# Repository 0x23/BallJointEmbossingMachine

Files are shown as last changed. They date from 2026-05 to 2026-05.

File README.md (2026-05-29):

# Ball Joint Embossing Machine

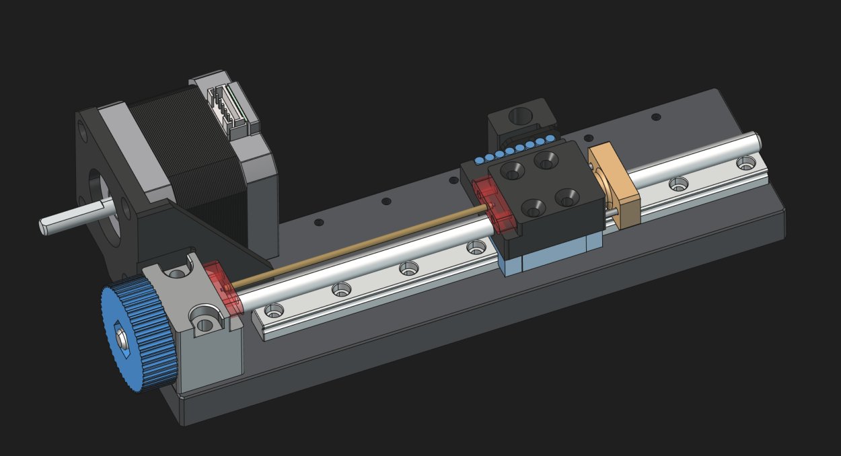
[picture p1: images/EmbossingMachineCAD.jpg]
CAD render of the embossing machine


> **Work in Progress** — This project is not in a finished, well-documented, or ready-to-replicate state. It is shared as a starting point for anyone who wants to build upon it. Expect incomplete documentation, rough edges, and parts that may require adaptation.

## Overview

A motorized linear embossing machine designed to precisely press ball joints. It was designed to automate the production of balljoint linkages for the [Open-Micro-Manipulator](https://github.com/0x23/MicroManipulatorStepper). It uses a NEMA 17 stepper motor driving a leadscrew on an MGN9 linear rail, with closed-loop position feedback from an MT6835 magnetic encoder. The tool head position is controlled in real time by firmware running on an RP2040 microcontroller.

Watch the video on YouTube (https://youtu.be/NM2KXvRGmpg)

## Hardware

- **Microcontroller:** RP2040-ZERO / RP2350-ZERO
- **Motor:** NEMA 17 stepper (1.8°, 50 pole pairs)
- **Motor driver:** TB6612
- **Position sensor:** MT6835 magnetic encoder (SPI)
- **Linear guide:** MGN9 rail + carriage
- **Drive:** Leadscrew with 3 mm magnet pitch, 48/20 gear ratio

## Electronics

> **WARNING: The electronics must be powered by no more than 5 V. Supplying a higher voltage will risk damaging the USB port on your Computer.**

The custom controller board (`electronics/ControllerBoardSingle_v1/`) is designed around the RP2040-ZERO / RP2350-ZERO and the TB6612 dual motor driver. Open the project with KiCad 10 or later. There is alwas a physical button to start the embossing process - please look at the firmware for finding the correct pin.

## Firmware

The firmware is built with [PlatformIO](https://platformio.org/).

**Build & upload:**
```bash
cd firmware
pio run --target upload
```

**Linux note:** udev rules must be installed before the upload will work:
```bash
sudo curl -fsSL https://raw.githubusercontent.com/platformio/platformio-core/develop/platformio/assets/system/99-platformio-udev.rules \
  -o /etc/udev/rules.d/99-platformio-udev.rules
sudo service udev restart
# replug the device, then run pio run --target upload
```

## License

MIT — see [LICENSE](LICENSE) for the full text.

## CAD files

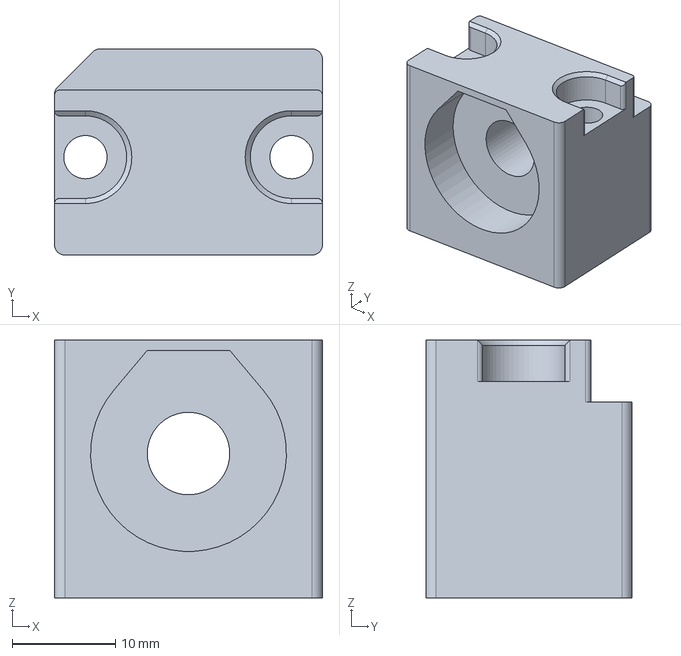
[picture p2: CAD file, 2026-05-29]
construction/ToolpostFixed.FCStd
26.0 x 20.0 x 25.0 mm

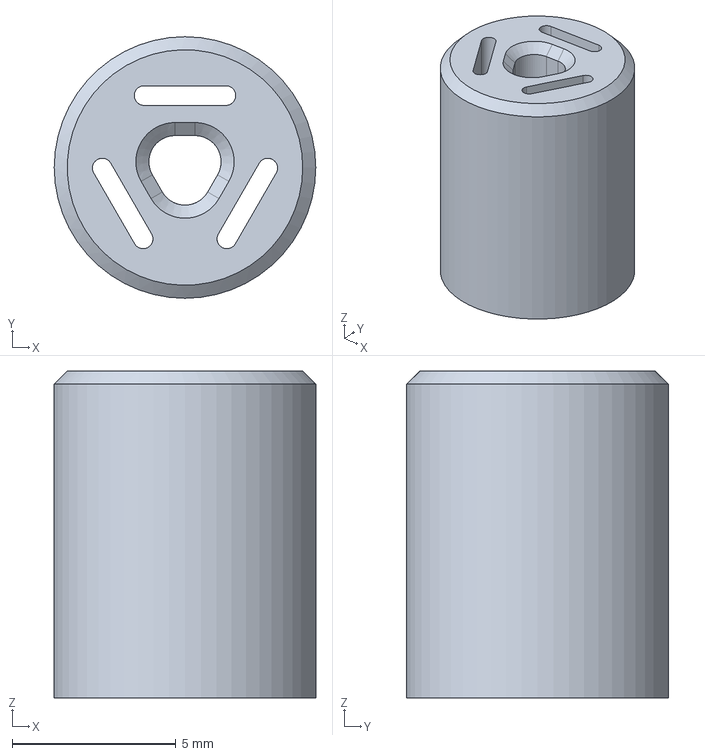
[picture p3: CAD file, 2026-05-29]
construction/RodAlignmentCollet.FCStd
8.00 x 8.00 x 10.0 mm

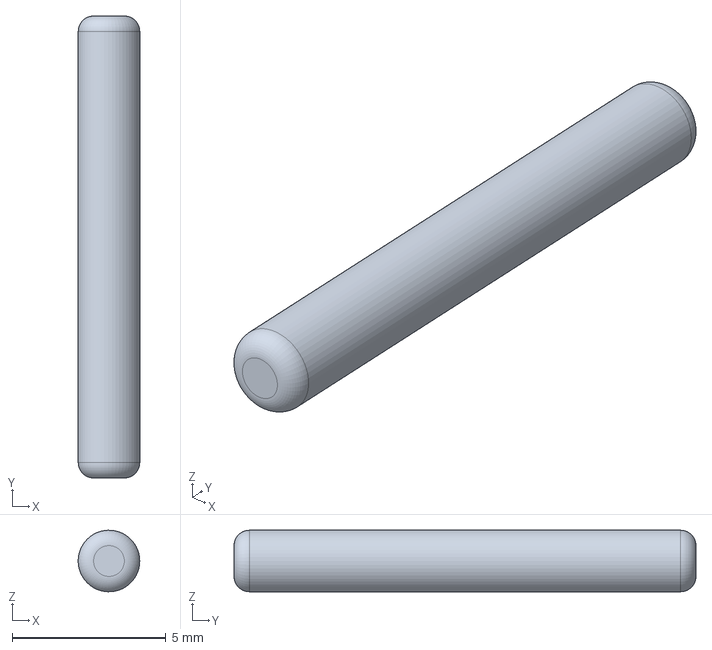
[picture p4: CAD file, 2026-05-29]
construction/TorquePin.FCStd
2.00 x 15.0 x 2.00 mm

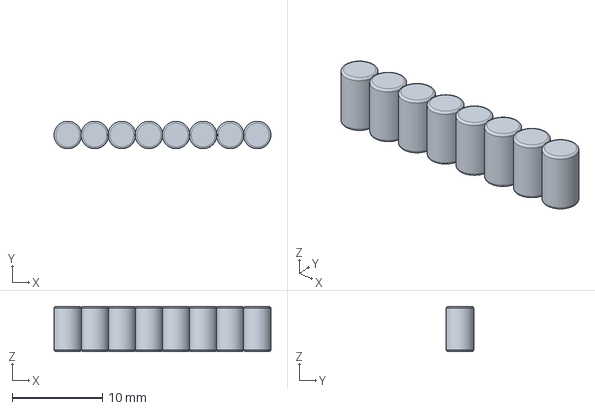
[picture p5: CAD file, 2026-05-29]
construction/EncoderMagnetArray.FCStd
24.0 x 3.05 x 5.00 mm

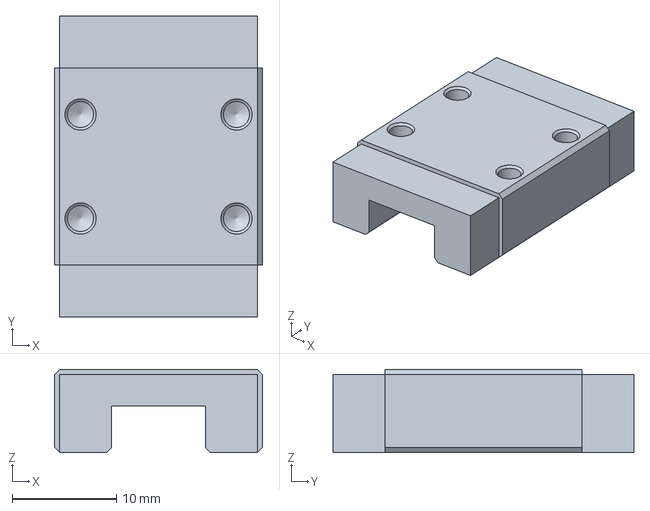
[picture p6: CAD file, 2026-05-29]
construction/Mgn9Carriage.FCStd
20.0 x 28.9 x 8.00 mm

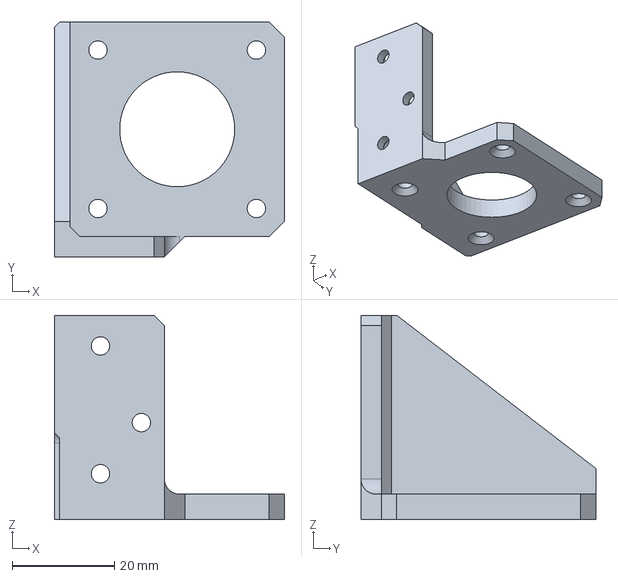
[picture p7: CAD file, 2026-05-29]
construction/MotorMount.FCStd
45.0 x 46.0 x 40.0 mm

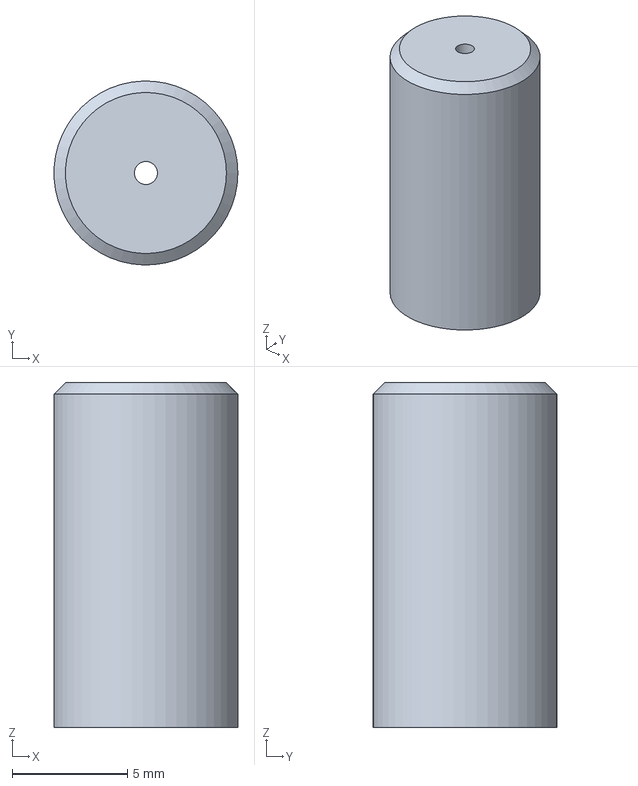
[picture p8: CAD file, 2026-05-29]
construction/ToolHeadRodGuide.FCStd
7.99 x 8.00 x 15.0 mm

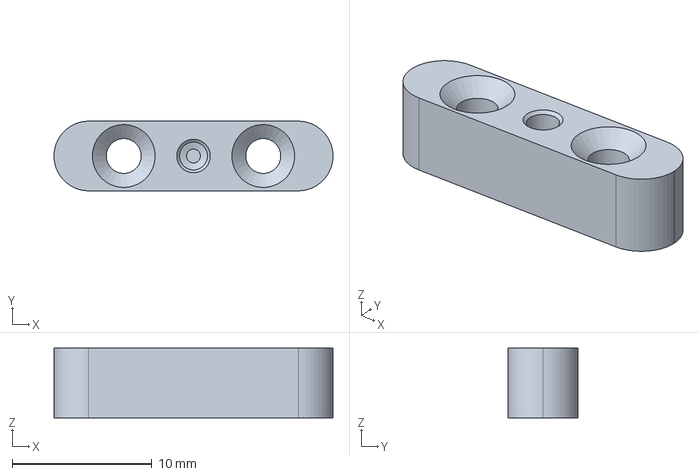
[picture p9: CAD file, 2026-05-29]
construction/ToolHead.FCStd
20.0 x 5.00 x 5.00 mm

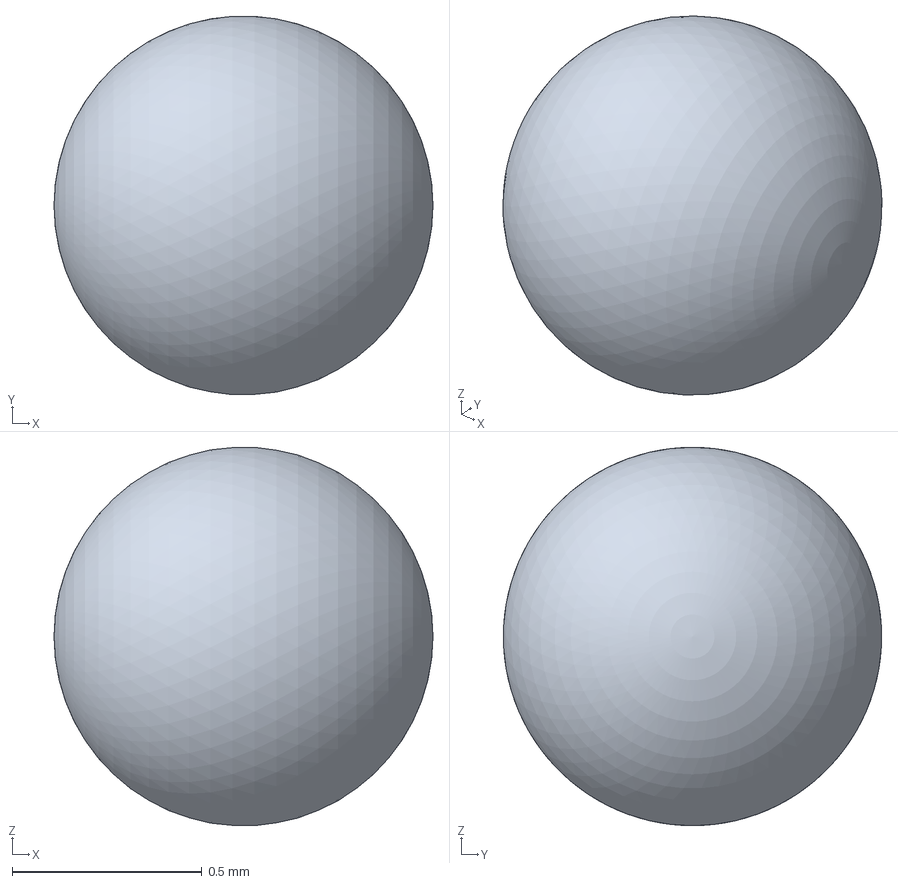
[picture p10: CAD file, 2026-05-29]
construction/Ball.FCStd
1.00 x 0.998 x 0.998 mm

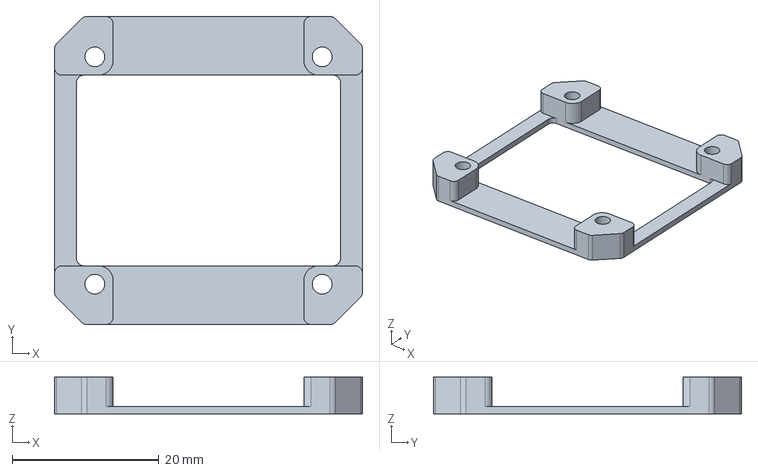
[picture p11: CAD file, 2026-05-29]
construction/PcbMount.FCStd
42.0 x 42.0 x 5.00 mm

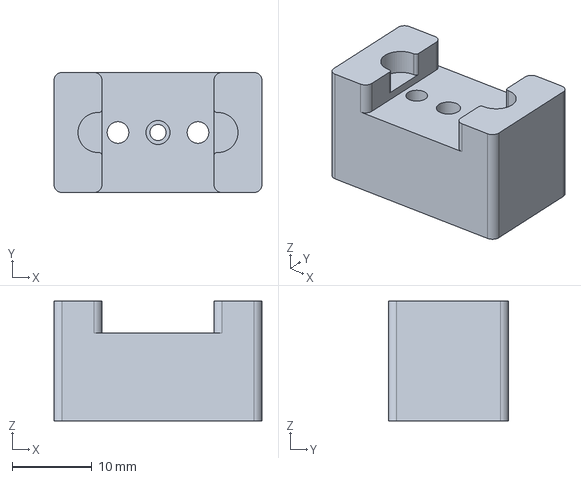
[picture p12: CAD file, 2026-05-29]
construction/ToolHeadDrillGuideB.FCStd
26.0 x 15.0 x 15.0 mm

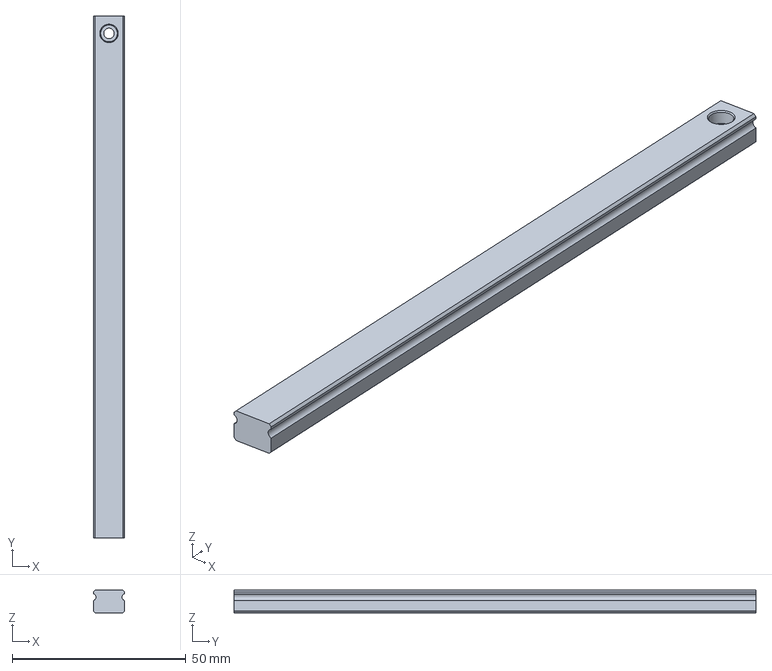
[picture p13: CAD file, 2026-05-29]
construction/Mgn9Rail.FCStd
9.00 x 150.0 x 6.50 mm

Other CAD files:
construction/Asm_Encoder.FCStd
construction/Asm_EmbossingTool.FCStd
construction/Asm_ToolpostMoving.FCStd
construction/Asm_ToolMoving.FCStd
construction/Asm_Mgn9Rail.FCStd
construction/Asm_ToolFixed.FCStd
construction/Base.FCStd
construction/BuckleGuard.FCStd
construction/DriveGear.FCStd
construction/DriveNut.FCStd
construction/EncoderMount.FCStd
construction/Leadscrew.FCStd
construction/LeadscrewBearing.FCStd
construction/LeadscrewBushing.FCStd
construction/MT6835.FCStd
construction/Rod.FCStd
construction/StepperMotorNema17.FCStd
construction/ToolHeadDrillGuideA.FCStd
construction/ToolpostMoving.FCStd

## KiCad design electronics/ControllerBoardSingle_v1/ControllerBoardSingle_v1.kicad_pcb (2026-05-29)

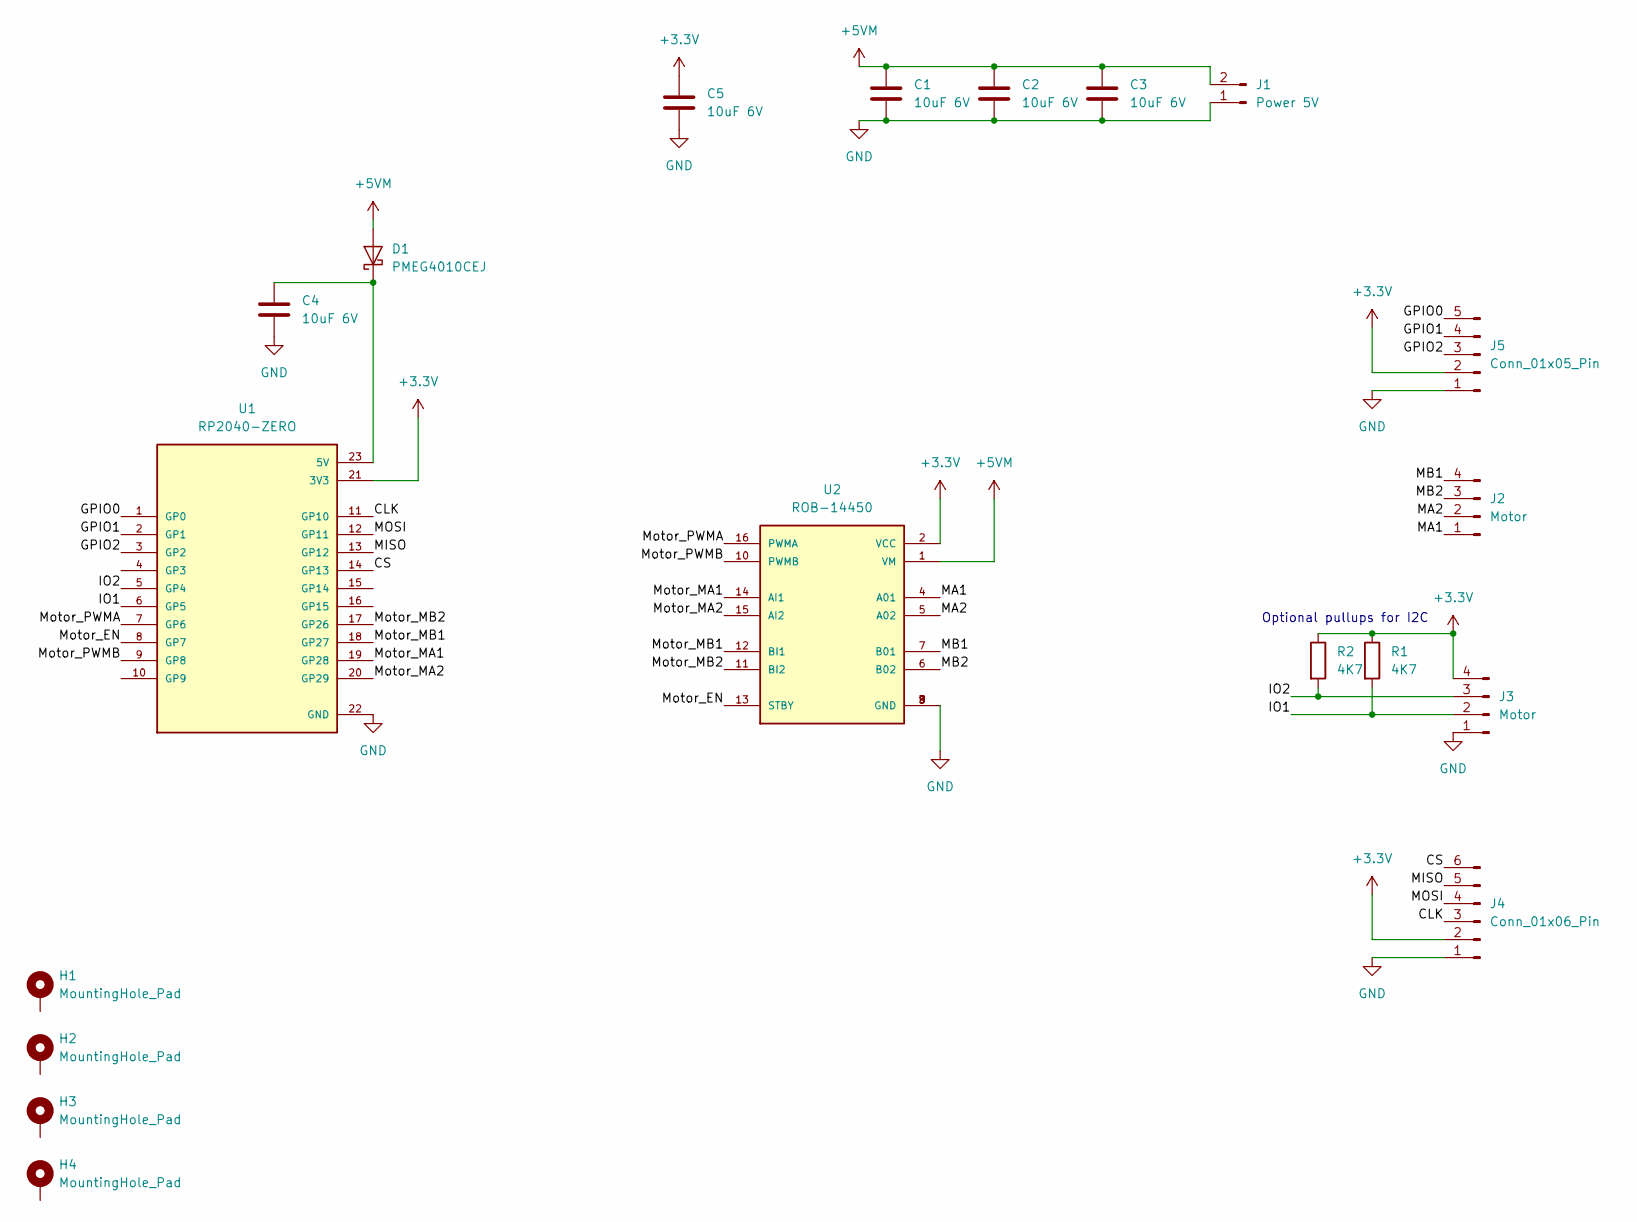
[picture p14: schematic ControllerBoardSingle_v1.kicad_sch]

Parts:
C1, C2, C3, C4, C5: 10uF 6V; C_0805_2012Metric_Pad1.18x1.45mm_HandSolder
D1: PMEG4010CEJ; D_SOD-123F
H1, H2, H3, H4: MountingHole_Pad; MountingHole_3.2mm_M3_ISO7380_Pad
J1: Power 5V; PinHeader_1x02_P2.54mm_Horizontal
J2, J3: Motor; JST_PH_B4B-PH-K_1x04_P2.00mm_Vertical
J4: Conn_01x06_Pin; JST_PH_B6B-PH-K_1x06_P2.00mm_Vertical
J5: Conn_01x05_Pin; PinSocket_1x05_P2.00mm_Vertical
R1, R2: 4K7; R_0603_1608Metric_Pad0.98x0.95mm_HandSolder
U1: RP2040-ZERO; MODULE_RP2040-ZERO; PARTREV NA
U2: ROB-14450; MODULE_ROB-14450; PARTREV 11-13-17

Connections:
+3.3V: C5.1, J3.4, J4.2, J5.2, R1.1, R2.1, U1.21 (3V3), U2.2 (VCC)
+5VM: C1.1, C2.1, C3.1, D1.2 (A), J1.2, U2.1 (VM)
/CLK: J4.3, U1.11 (GP10)
/CS: J4.6, U1.14 (GP13)
/GPIO0: J5.5, U1.1 (GP0)
/GPIO1: J5.4, U1.2 (GP1)
/GPIO2: J5.3, U1.3 (GP2)
/IO1: J3.2, R1.2, U1.6 (GP5)
/IO2: J3.3, R2.2, U1.5 (GP4)
/MA1: J2.1, U2.4 (A01)
/MA2: J2.2, U2.5 (A02)
/MB1: J2.4, U2.7 (B01)
/MB2: J2.3, U2.6 (B02)
/MISO: J4.5, U1.13 (GP12)
/MOSI: J4.4, U1.12 (GP11)
/Motor_EN: U1.8 (GP7), U2.13 (STBY)
/Motor_MA1: U1.19 (GP28), U2.14 (AI1)
/Motor_MA2: U1.20 (GP29), U2.15 (AI2)
/Motor_MB1: U1.18 (GP27), U2.12 (BI1)
/Motor_MB2: U1.17 (GP26), U2.11 (BI2)
/Motor_PWMA: U1.7 (GP6), U2.16 (PWMA)
/Motor_PWMB: U1.9 (GP8), U2.10 (PWMB)
GND: C1.2, C2.2, C3.2, C4.2, C5.2, J1.1, J3.1, J4.1, J5.1, U1.22 (GND), U2.3 (GND), U2.8 (GND), U2.9 (GND)
unnamed: C4.1, D1.1 (K), U1.23 (5V)

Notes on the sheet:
Optional pullups for I2C

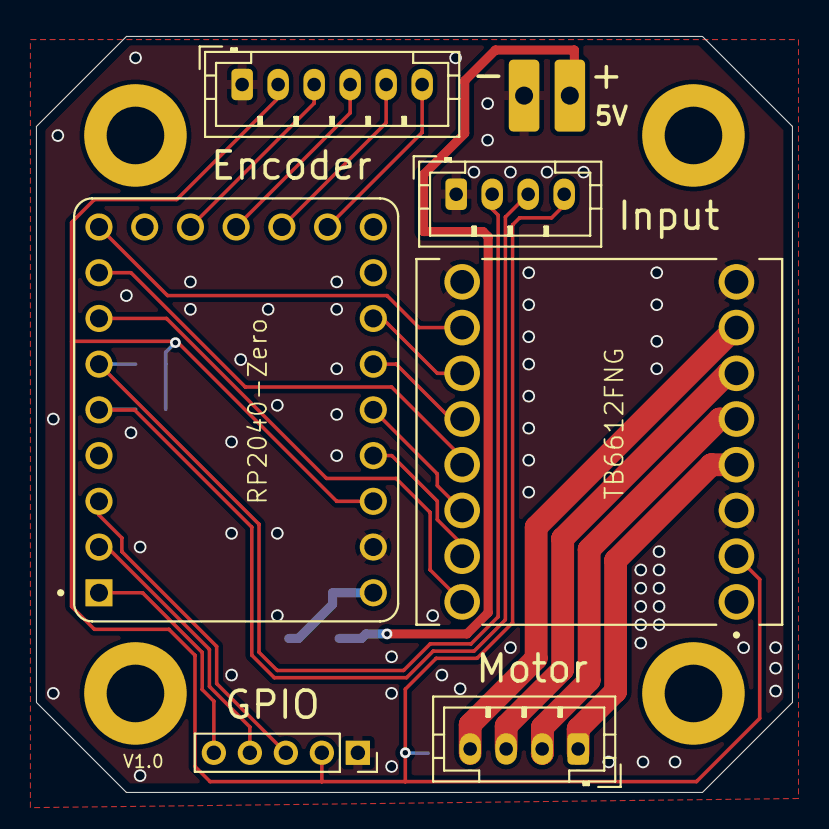
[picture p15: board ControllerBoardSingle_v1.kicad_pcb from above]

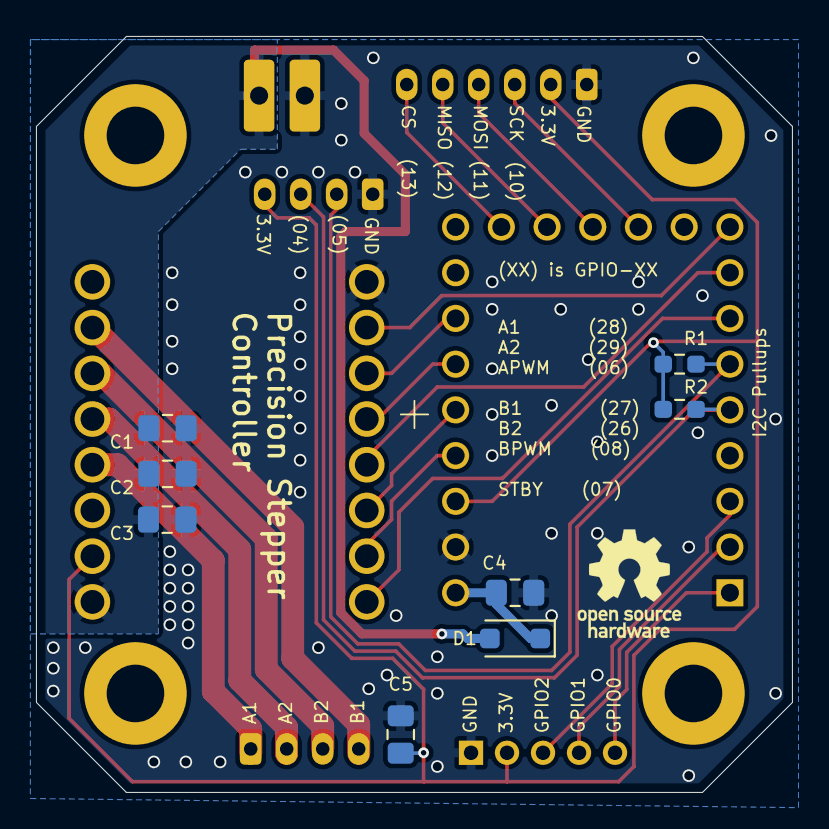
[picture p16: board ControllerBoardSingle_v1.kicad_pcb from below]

Board: 2 copper layers, 42.0 x 42.0 mm, 19 parts (8 on the bottom side), 24 nets.

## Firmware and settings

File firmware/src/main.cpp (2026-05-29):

// --------------------------------------------------------------------------------------
// Project: MicroManipulatorStepper
// License: MIT (see LICENSE file for full description)
//          All text in here must be included in any redistribution.
// Author:  M. S. (diffraction limited)
// --------------------------------------------------------------------------------------

#include "main.h"

#include "hardware/clocks.h"
#include "hardware/pll.h"
#include "hardware/vreg.h"

#include <NeoPixelConnect.h>
#include <Wire.h>
#include <algorithm>

#include "hardware/MT6835_encoder.h"
#include "hardware/TB6612_motor_driver.h"
#include "utilities/logging.h"
#include "utilities/math_constants.h"
#include "utilities/frequency_counter.h"
#include "version.h"
#include "hw_config.h"

//*** GLOBALS ***************************************************************************

MT6835Encoder encoder(ENCODER_SPI, PIN_ENCODER_CS);


TB6612MotorDriver motor_driver(
  PIN_MOTOR_EN, PIN_M_PWM_A_POS, PIN_M_PWM_A_NEG, PIN_MOTOR_PWMA,
  PIN_MOTOR_EN, PIN_M_PWM_B_POS, PIN_M_PWM_B_NEG, PIN_MOTOR_PWMB
);

NeoPixelConnect strip(PIN_BUILTIN_LED, 1);

//*** CLASS *****************************************************************************

class EmbossingController {
  public:
    EmbossingController(TB6612MotorDriver* motor_driver, MT6835Encoder* encoder) {
      EmbossingController::encoder = encoder;
      EmbossingController::motor_driver = motor_driver;

      encoder_angle_to_distance = -2*ENCODER_MAGNET_PITCH/Constants::TWO_PI_F;
      pos_to_field_angle = Constants::TWO_PI_F*MOTOR_POLE_PAIRS*ROTATIONS_PER_MM;
      rapid_velocity = 1.3f;
      embossing_velocity = 0.2f;

      target_encoder_value = 0.0f;
      measurement_pos = 0.0f;
      motor_position = 0.0f;
      collision_motor_pos = 0.0f;
    }

    void set_target_encoder_value(float target_value) {
      EmbossingController::target_encoder_value = target_value;
    }

    void set_measurement_pos(float pos) {
     EmbossingController::measurement_pos = pos;
    }

    bool init(float target_length_offset=0.0f) {
      bool init_ok = find_collision(3.0f); // find collision
      collision_motor_pos = get_motor_pos();

      if(init_ok == false)
        return false;

      // back off from collision point
      move_to_ex(collision_motor_pos+1.0f, 1.5f, 1.0f);

      // store position for measurement
      set_measurement_pos(get_motor_pos());

      // use length measurement as target length
      float target_pos = read_encoder_pos();
      set_target_encoder_value(target_pos+target_length_offset);

      return true;
    }

    void run_embossing(float start_length_offset=0.0f) {
      float embossing_start_pos = collision_motor_pos+start_length_offset;
      float p = collision_motor_pos+start_length_offset;

      while(true) {
        float error = measure_length_error(false);
        LOG_RAW(">lenght_error: %f", error);
        if(error<0.0f)
          break;

        p -= error*0.9f;
        move_to_ex(embossing_start_pos, rapid_velocity, 1.0f);
        move_to_ex(p, 0.3, 0.6f);
       // move_to_ex(collision_motor_pos, 0.3, 0.6f);
      }

      move_to_ex(measurement_pos, rapid_velocity, 1.0f);
    }

    float measure_length_error(bool move_to_prev_pos) {
      float prev_motor_pos = get_motor_pos();
      move_to_ex(measurement_pos, rapid_velocity, 1.0f);
      sleep_ms(50);
      float enc_pos = read_encoder_pos();
      sleep_ms(50);
      
      // return to previous pos
      if(move_to_prev_pos)
        move_to_ex(prev_motor_pos, rapid_velocity, 1.0f);

      return enc_pos-target_encoder_value;
    }

    void move_to_ex(float pos, float velocity, float current) {
      motor_driver->set_amplitude_smooth(current, 0.1);
      move_to(pos, velocity);
      motor_driver->set_amplitude_smooth(0.3, 0.1);
    }

    void move_to(float pos, float velocity) {
      float delta = pos-motor_position;
      motor_driver->rotate_field(delta*pos_to_field_angle, velocity*pos_to_field_angle, [this](){
        // update encoder regularily
        encoder->read_abs_angle();
      });
      motor_position += delta;
    }

    float get_motor_pos() {
      return motor_position;
    }

    float read_encoder_pos() {
      return encoder->read_abs_angle()*encoder_angle_to_distance;
    }

    bool find_collision(float search_range, float velocity=0.2f) {
      float step = -0.05;
      float detection_delta = 0.05;
      float start_pos = get_motor_pos();
      float start_encoder_value = read_encoder_pos();
      
      for(int i=0; i<(int)abs(search_range/step); i++) {
        move_to(start_pos + step*i, velocity);
        if(start_encoder_value-read_encoder_pos() > detection_delta) {
          LOG_INFO("Collision detected");
          return true;
        }
      }

      LOG_INFO("No collision within searchrange found");
      return false;
    }

  private:
    MT6835Encoder* encoder;
    TB6612MotorDriver* motor_driver;

    float target_encoder_value;
    float measurement_pos;
    float embossing_velocity;
    float rapid_velocity;

    float collision_motor_pos;

    float motor_position;
    float encoder_angle_to_distance;
    float pos_to_field_angle;
};

EmbossingController embossing_controller(&motor_driver, &encoder);

//*** FUNCTIONS *************************************************************************

void set_led_color(uint8_t r, uint8_t g, uint8_t b) {
  strip.neoPixelSetValue(0, r, g, b, false);
  sleep_us(2000);
  strip.neoPixelShow();
}

void led_blink(uint8_t r, uint8_t g, uint8_t b, int count, int period_time_ms) {
  for(int i=0; i<count; i++) {
    set_led_color(r, g, b);
    sleep_ms(period_time_ms/2);
    set_led_color(0, 0, 0);
    sleep_ms(period_time_ms/2);
  }
}

void setup() {
  sleep_ms(100);  // Allow time for serial monitor to connect
  led_blink(0, 0, 10, 3, 100);

  Logger::instance().begin(115200, false);
  //while(!Serial);
  sleep_ms(100);  // Allow time for serial monitor to connect
  
  LOG_INFO("\n\nBall Joint Embossing ToolFirmware: %s", FIRMWARE_VERSION);

  MT6835Encoder::setup_spi(ENCODER_SPI, PIN_ENCODER_SCK, PIN_ENCODER_MOSI, PIN_ENCODER_MISO, 1000000);
  encoder.init(0x5, 0x4);

  motor_driver.begin();
  motor_driver.set_amplitude_smooth(0.3, 0.5);
  motor_driver.enable();

  pinMode(PIN_USER_BUTTON, INPUT_PULLUP);

  set_led_color(10, 4, 0);
  bool ok = embossing_controller.init(-0.00f);
  if(ok == false) {
    set_led_color(10, 0, 0);
    while(true);
  }

  set_led_color(0, 2, 0);
  LOG_INFO("Initialization finished");
  LOG_INFO(" ");

    // embossing_controller.move_to(1.0f, 0.5f);
}

float t = 0.0f;
void loop() {
  // wait for button
  while(digitalRead(PIN_USER_BUTTON) == true) {
    set_led_color(0, 10, 0);
    float error = embossing_controller.measure_length_error(false);
    LOG_RAW(">lenght_error: %f", error);
    sleep_ms(500);
  }

  set_led_color(10, 0, 10);
  embossing_controller.run_embossing();

  //float pos = embossing_controller.read_encoder_pos();
  //LOG_RAW(">encoder_poss: %f", pos);

//  sleep_ms(1000);

//  float abs_angle = encoder.read_abs_angle();
//  LOG_RAW(">angle: %f", abs_angle);

  //t = t*0.9f + abs_angle*0.1f;
  //motor_driver.set_field_angle(t*MOTOR_POLE_PAIRS);
//  t += 0.1f;
//  sleep_ms(10);  // Allow time for serial monitor to connect
}

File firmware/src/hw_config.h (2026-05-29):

// motor pole pair count
//  * 100 for 0.9deg stepper motors
//  * 50  for 1.8deg stepper motors
#define MOTOR_POLE_PAIRS 50
#define ROTATIONS_PER_MM (48.0f/20.0f/1.0f)
#define ENCODER_MAGNET_PITCH 3.0f

// Single Axis Board
#define PIN_BUILTIN_LED 16
#define PIN_USER_BUTTON PIN_GPIO_2

#define PIN_GPIO_0 0
#define PIN_GPIO_1 1
#define PIN_GPIO_2 2

#define PIN_M_PWM_A_POS  28
#define PIN_M_PWM_A_NEG  29
#define PIN_M_PWM_B_POS  27
#define PIN_M_PWM_B_NEG  26

#define PIN_MOTOR_EN      7
#define PIN_MOTOR_PWMA    6
#define PIN_MOTOR_PWMB    8

// note single axis board uses spi1
#define ENCODER_SPI spi1
#define PIN_ENCODER_CS 13
#define PIN_ENCODER_SCK 10
#define PIN_ENCODER_MISO 12
#define PIN_ENCODER_MOSI 11

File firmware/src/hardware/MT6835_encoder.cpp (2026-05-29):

// --------------------------------------------------------------------------------------
// This code is a modified version of the MT6835 Driver from the SimpleFOC project
// being distributed under the MIT liscence as well. Thank you SimpleFOC !
// --------------------------------------------------------------------------------------

#include "MT6835_encoder.h"
#include "hardware/spi.h"
#include "hardware/gpio.h"
#include "pico/stdlib.h"
#include "utilities/logging.h"

void MT6835Encoder::setup_spi(spi_inst_t* spi, uint pin_sck, uint pin_mosi, uint pin_miso, int32_t baudrate_hz) {
  // Set GPIO functions to SPI
  gpio_set_function(pin_sck, GPIO_FUNC_SPI);
  gpio_set_function(pin_mosi, GPIO_FUNC_SPI);
  gpio_set_function(pin_miso, GPIO_FUNC_SPI);
  
  // Defensive: disable pull-ups/downs
  gpio_disable_pulls(pin_sck);
  gpio_disable_pulls(pin_mosi);
  gpio_disable_pulls(pin_miso);
  
  // SPI format: 8 bits, mode 3 (CPOL=1, CPHA=1)
  spi_init(spi, baudrate_hz);
  spi_set_format(spi, 8, SPI_CPOL_1, SPI_CPHA_1, SPI_MSB_FIRST);
}

MT6835Encoder::MT6835Encoder(spi_inst_t* spi, uint cs_pin) : spi(spi), cs_pin(cs_pin) {
  // nop
}

MT6835Encoder::~MT6835Encoder() {
  // nop
}

void MT6835Encoder::init(uint8_t bandwidth, uint8_t hysteresis) {
  if (cs_pin >= 0) {
      gpio_init(cs_pin);
      gpio_set_dir(cs_pin, GPIO_OUT);
      gpio_put(cs_pin, 1);  // CS high
  }

  set_rotation_direction(0);    // needs to be set, otherwise might be random
  set_bandwidth(bandwidth);
  set_hysteresis(hysteresis);

  last_raw_angle = 0;
  abs_raw_angle = 0;
}

void MT6835Encoder::reset_abs_angle(int32_t abs_raw_angle) {
  MT6835Encoder::abs_raw_angle = abs_raw_angle;
}

void MT6835Encoder::reset_abs_angle_period() {
  abs_raw_angle %= MT6835_CPR;
  if (abs_raw_angle < 0)
    abs_raw_angle += MT6835_CPR;
}

float MT6835Encoder::read_abs_angle() {
  int32_t raw_angle = read_abs_angle_raw();
  return raw_angle * RAW_TO_ANGLE;
}

MT6835Encoder::AbsRawAngleType MT6835Encoder::read_abs_angle_raw() {
  uint8_t data[6] = {0};
  data[0] = MT6835_OP_ANGLE << 4;
  data[1] = MT6835_REG_ANGLE1;
  // rest zero

  spi_begin_transaction();
  spi_transfer(data, 6);
  spi_end_transaction();

  last_status = data[4] & 0x07;
  last_crc = data[5];
  int32_t raw_angle = ((int32_t)data[2] << 13) | ((int32_t)data[3] << 5) | (data[4] >> 3);
  
  if (check_crc) {
      if (last_crc != calc_crc(raw_angle, last_status)) {
          last_status |= MT6835_CRC_ERROR;
          return -1; // CRC error indicator
      }
  }

  return update_abs_raw_angle(raw_angle);
}

MT6835Encoder::AbsRawAngleType MT6835Encoder::get_last_abs_raw_angle() const {
  return abs_raw_angle;
}

float MT6835Encoder::get_last_abs_angle() const {
  return abs_raw_angle * RAW_TO_ANGLE;
}

int32_t MT6835Encoder::get_rawcounts_per_rev() {
  return MT6835_CPR;
}

uint8_t MT6835Encoder::get_status() {
    return last_status;
}

uint8_t MT6835Encoder::get_calibration_status() {
    uint8_t data[3] = {0};
    data[0] = (MT6835_OP_READ << 4) | (MT6835_REG_CAL_STATUS >> 8);
    data[1] = MT6835_REG_CAL_STATUS & 0xFF;

    spi_begin_transaction();
    spi_transfer(data, 3);
    spi_end_transaction();

    return data[2] >> 6;
}

bool MT6835Encoder::set_zero_from_current_position() {
    MT6835Command cmd{};
    cmd.cmd = MT6835_OP_ZERO;
    cmd.addr = 0x000;
    transfer_24(&cmd);
    abs_raw_angle = 0;
    last_raw_angle = 0;
    return cmd.data == MT6835_WRITE_ACK;
}

bool MT6835Encoder::write_eeprom() {
    sleep_ms(1); // wait at least 1 ms
    MT6835Command cmd{};
    cmd.cmd = MT6835_OP_PROG;
    cmd.addr = 0x000;
    transfer_24(&cmd);
    return cmd.data == MT6835_WRITE_ACK;
}

uint8_t MT6835Encoder::get_bandwidth() {
    MT6835Options5 opts{ .reg = read_register(MT6835_REG_OPTS5) };
    return opts.bw;
}
void MT6835Encoder::set_bandwidth(uint8_t bw) {
    MT6835Options5 opts{ .reg = read_register(MT6835_REG_OPTS5) };
    opts.bw = bw;
    write_register(MT6835_REG_OPTS5, opts.reg);
}

uint8_t MT6835Encoder::get_hysteresis() {
    MT6835Options3 opts{ .reg = get_options3().reg };
    return opts.hyst;
}
void MT6835Encoder::set_hysteresis(uint8_t hyst) {
    MT6835Options3 opts{ .reg = get_options3().reg };
    opts.hyst = hyst;
    set_options3(opts);
}

uint8_t MT6835Encoder::get_rotation_direction() {
    MT6835Options3 opts{ .reg = get_options3().reg };
    return opts.rot_dir;
}
void MT6835Encoder::set_rotation_direction(uint8_t dir) {
    MT6835Options3 opts{ .reg = get_options3().reg };
    opts.rot_dir = dir;
    set_options3(opts);
}

uint16_t MT6835Encoder::get_abz_resolution() {
    uint8_t hi = read_register(MT6835_REG_ABZ_RES1);
    MT6835ABZRes lo{ .reg = read_register(MT6835_REG_ABZ_RES2) };
    return (hi << 6) | lo.abz_res_low;
}
void MT6835Encoder::set_abz_resolution(uint16_t res) {
    uint8_t hi = (res >> 6);
    MT6835ABZRes lo{ .reg = read_register(MT6835_REG_ABZ_RES2) };
    lo.abz_res_low = (res & 0x3F);
    write_register(MT6835_REG_ABZ_RES1, hi);
    write_register(MT6835_REG_ABZ_RES2, lo.reg);
}

bool MT6835Encoder::is_abz_enabled() {
    MT6835ABZRes lo{ .reg = read_register(MT6835_REG_ABZ_RES2) };
    return lo.abz_off == 0;
}
void MT6835Encoder::set_abz_enabled(bool enabled) {
    MT6835ABZRes lo{ .reg = read_register(MT6835_REG_ABZ_RES2) };
    lo.abz_off = enabled ? 0 : 1;
    write_register(MT6835_REG_ABZ_RES2, lo.reg);
}

bool MT6835Encoder::is_ab_swapped() {
    MT6835ABZRes lo{ .reg = read_register(MT6835_REG_ABZ_RES2) };
    return lo.ab_swap == 1;
}
void MT6835Encoder::set_ab_swapped(bool swapped) {
    MT6835ABZRes lo{ .reg = read_register(MT6835_REG_ABZ_RES2) };
    lo.ab_swap = swapped ? 1 : 0;
    write_register(MT6835_REG_ABZ_RES2, lo.reg);
}

uint16_t MT6835Encoder::get_zero_position() {
    uint8_t hi = read_register(MT6835_REG_ZERO1);
    MT6835Options0 lo{ .reg = read_register(MT6835_REG_ZERO2) };
    return (hi << 4) | lo.zero_pos_low;
}
void MT6835Encoder::set_zero_position(uint16_t pos) {
    uint8_t hi = (pos >> 4);
    MT6835Options0 lo{ .reg = read_register(MT6835_REG_ZERO2) };
    lo.zero_pos_low = pos & 0x0F;
    write_register(MT6835_REG_ZERO1, hi);
    write_register(MT6835_REG_ZERO2, lo.reg);
}

MT6835Options1 MT6835Encoder::get_options1() {
    MT6835Options1 result{ .reg = read_register(MT6835_REG_OPTS1) };
    return result;
}
void MT6835Encoder::set_options1(MT6835Options1 opts) {
    write_register(MT6835_REG_OPTS1, opts.reg);
}

MT6835Options2 MT6835Encoder::get_options2() {
    MT6835Options2 result{ .reg = read_register(MT6835_REG_OPTS2) };
    return result;
}
void MT6835Encoder::set_options2(MT6835Options2 opts) {
    MT6835Options2 val = get_options2();
    val.nlc_en = opts.nlc_en;
    val.pwm_fq = opts.pwm_fq;
    val.pwm_pol = opts.pwm_pol;
    val.pwm_sel = opts.pwm_sel;
    write_register(MT6835_REG_OPTS2, val.reg);
}

MT6835Options3 MT6835Encoder::get_options3() {
    MT6835Options3 result{ .reg = read_register(MT6835_REG_OPTS3) };
    return result;
}
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
